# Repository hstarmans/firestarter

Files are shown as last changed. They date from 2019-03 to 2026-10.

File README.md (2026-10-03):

# Hexastorm PCB

KiCad design files for **Hexastorm**, an open-hardware laser direct imager (LDI). An ESP32-S3 handles communication and motion control, while an iCE40 UP5K FPGA generates synchronized laser pulses for the rotating polygon prism.

The design files are organized into two parts:

## 1. Laser Module

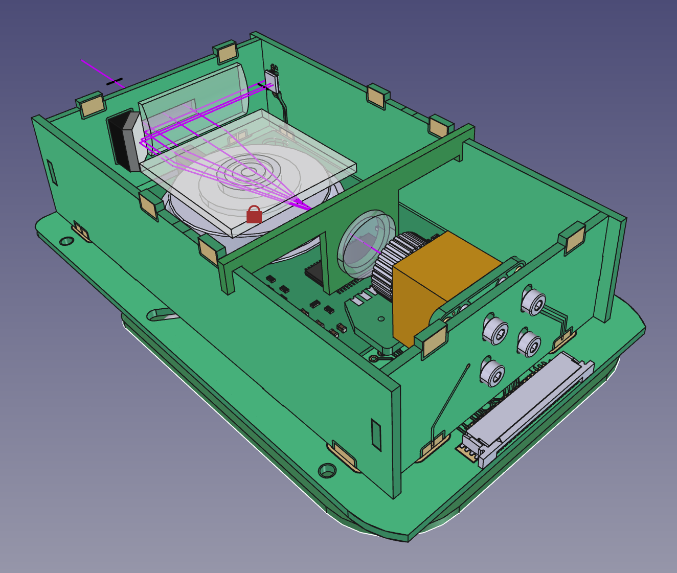
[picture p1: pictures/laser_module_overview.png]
Laser Module Assembly


PCBs forming the scanhead assembly (see [hexastorm_design](https://github.com/hstarmans/hexastorm_design) for complete CAD):

* **Prism Drive:** PCBs to spin the optical prism using either an external BLDC motor or an experimental PCB stator motor.
* **Laser Control:** Diode driver and photodiode sync circuit.
* **Maxwell Dock:** Receiver PCB with kinematic ball mounts and magnet sockets.

## 2. Base Board

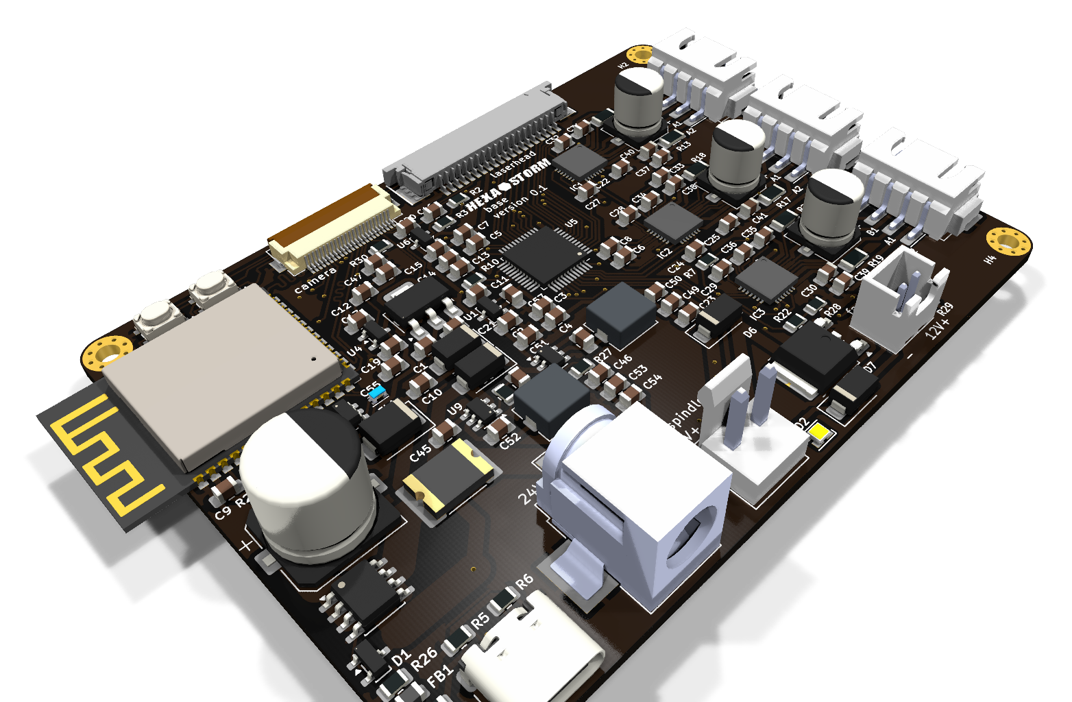
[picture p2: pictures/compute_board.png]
Hexastorm Compute Board


Single-board controller for 3-axis motion and laser timing. Intended for desktop CNC frames (such as the CNC 3018 Pro, for which it is a drop-in replacement):

* **MCU:** ESP32-S3 (N32R8V) with 8MB Octal PSRAM for line buffers.
* **FPGA:** Lattice iCE40 UP5K for laser pulse timing synced to the prism photodiode index.
* **Camera:** 24-pin FPC connector for an OV2640 camera module.
* **Motion:** Sockets for 3x stepper drivers (TMC2209) for X, Y, and Z axes.
* **Laser:** Header for one laser scanhead.
* **Power:** 24V input with onboard 12V buck regulator for the laser module and cooling fan.
* **USB:** USB-C for data and flashing.

---

# Resources & Links

* **Blog & Build Logs:** [Hackaday.io project](https://hackaday.io/project/21933-open-hardware-fast-high-resolution-laser)
* **BOM & Costing:** Generated with [KiCost](https://github.com/hildogjr/KiCost) (see [developer.md](developer.md))
* **CAD Files:** [hexastorm_design](https://github.com/hstarmans/hexastorm_design)
* **Optical Simulation:** [opticaldesign](https://github.com/hstarmans/opticaldesign)

# Status

* **Exposure Verification:** High-resolution optical scanning and exposure have been validated in hardware (see [demonstration video](https://youtu.be/dR09Tev0cPk)).
* **Base Board:** Fabricated, tested, and verified functional (ESP32-S3, iCE40 UP5K FPGA, stepper drivers, and power regulation).
* **Laser Module:** Scanhead structure, optics, diode driver, and kinematic docking are verified. The integrated PCB stator motor concept is proven, though the latest stator board revision has not yet been tested.

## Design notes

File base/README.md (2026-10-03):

# Hexastorm Compute Board

Hexastorm Compute Board

Main single-board controller for the Hexastorm laser direct imager (LDI). Integrates high-speed optical timing logic, motion control, and power distribution on a 4-layer PCB designed as a drop-in replacement for desktop CNC 3018 frames.

## Key Details
* **MCU:** ESP32-S3 (N32R8V) with 8MB Octal PSRAM for line buffers and web/USB interface
* **FPGA:** Lattice iCE40 UltraPlus 5K (UP5K) for nanosecond laser pulse timing synchronized to prism index
* **Motion:** Sockets for 3× TMC2209 stepper motor drivers (X, Y, Z axes)
* **Vision:** 24-pin FPC connector for an OV2640 alignment camera
* **Laser Interface:** High-density header for scanhead interconnect
* **Power:** 24V input with onboard 12V buck regulator and 3.3V power stages
* **Connectivity:** USB-C for flashing and high-speed data transfer

---
*Part of the [Hexastorm (Firestarter)](../README.md) open-hardware laser direct imaging project.*

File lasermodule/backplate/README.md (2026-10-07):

# Scanhead Back Plate

Scanhead Back Plate

Structural rear wall of the laser scanhead enclosure box, providing mechanical rigidity and fastener mounting points.
It supplies current to the laserdiode via two strips to laser module.

## Key Details
* **Role:** Rear structural wall of scanhead enclosure
* **Material:** 1.6mm FR4 PCB material

---
*Part of the [Hexastorm (Firestarter)](../../README.md) open-hardware laser direct imaging project.*

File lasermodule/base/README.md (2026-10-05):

# Scanhead Base Plate

Scanhead Base Plate

Structural bottom floor of the laser scanhead module. Hosts mounting holes for the prism motor assembly, internal optics brackets, and kinematic docking interfaces.
A female pinheader is shown but this one is normally not placed.

## Key Details

* **Role:** Bottom structural plate of scanhead housing
* **Material:** 1.6mm FR4 PCB material
* **Features:** Prism spindle mounting, beam pass-through cutouts, interlocking tabs

---

*Part of the [Hexastorm (Firestarter)](../../README.md) open-hardware laser direct imaging project.*

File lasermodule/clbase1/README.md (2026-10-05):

# Cylindrical Lens Base (clbase1)

Cylindrical Lens Base (clbase1)

PCB-based optical bracket holding the first cylinder lens with a focal length of 75 mm  securely in position along the scanhead optical beam path.

## Key Details

* **Function:** Cylindrical lens mounting bracket
* **Material:** Rigid FR4 for thermal and mechanical stability
* **Interface:** Interlocking slots for alignment inside the scanhead chassis

---

*Part of the [Hexastorm (Firestarter)](../../README.md) open-hardware laser direct imaging project.*

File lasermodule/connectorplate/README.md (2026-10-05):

# Scanhead Connector Plate

Scanhead Connector Plate

Interface place between the polygon motor and the base pcb.

## Key Details

* **Role:** Electrical interconnect interface for scanhead
* **Connectors:** High-density locking connector cutout and strain relief

---

*Part of the [Hexastorm (Firestarter)](../../README.md) open-hardware laser direct imaging project.*

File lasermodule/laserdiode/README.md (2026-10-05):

# Laser Diode Mount & Driver PCB

Laser Diode Mount & Driver PCB

Carrier PCB for the laser diode module inside the scanhead housing. Provides pogo-pin connection to the back plate of the laserhead. Solder contacts provide opton to determine pin routing.

## Key Details

* **Function:** Laser diode mounting and modulation interface
* **Contacts:** Spring-loaded pogo pin pads and direct solder pads for high-speed modulation driver connection
* **Form Factor:** Compact circular/rectangular footprint fitting diode heatsink assembly

---

*Part of the [Hexastorm (Firestarter)](../../README.md) open-hardware laser direct imaging project.*

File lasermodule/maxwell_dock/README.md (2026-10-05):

# Maxwell Kinematic Dock Receiver Plate

Maxwell Kinematic Dock Receiver Plate

Precision kinematic dock receiver PCB interface. Provides high-repeatability magnetic and kinematic mounting for quickly swapping or aligning the laser toolhead.
The three circular holes are for metal balls which are glued to the board. The four smaller holes are for M2 screw. The two keep out areas are for the axis of the mirror motor and 
the connector pins.

## Key Details

* **Mounting Principle:** Exact-constraint Maxwell kinematic clamp
* **Features:** Alignment ball sockets, magnetic clamp cutouts, and central laser pass-through
* **Repeatability:** Sub-pixel optical alignment repeatability after head replacement

---

*Part of the [Hexastorm (Firestarter)](../../README.md) open-hardware laser direct imaging project.*

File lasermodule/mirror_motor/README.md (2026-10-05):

# Polygon Mirror Motor Driver PCB

Polygon Mirror Motor Driver PCB

High-speed brushless motor driver PCB for driving the high-RPM rotating optical polygon mirror assembly. This board should not be built and is not functional.
It is used as virtual model for pcb of the sharp AR160 polygon motor.

## Key Details

* **Function:** Polygon mirror BLDC driver and timing feedback
* **Sensors:** Hall-effect sensor inputs for high-precision speed stabilization

---

*Part of the [Hexastorm (Firestarter)](../../README.md) open-hardware laser direct imaging project.*

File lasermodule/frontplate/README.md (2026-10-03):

# Scanhead Front Plate

Scanhead Front Plate

Front wall of the scanhead enclosure. Features the precision optical scan slit through which the reflected laser beam exits towards the exposure bed.

## Key Details
* **Role:** Front enclosure wall and beam exit window
* **Features:** Laser scan slit aperture and structural interlocking tabs

---
*Part of the [Hexastorm (Firestarter)](../../README.md) open-hardware laser direct imaging project.*

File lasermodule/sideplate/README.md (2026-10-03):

# Scanhead Side Plate

Scanhead Side Plate

Structural side wall of the scanhead housing. Features castellated/interlocking tabs for rigid 3D box construction using PCB material.

## Key Details
* **Role:** Structural side wall of scanhead
* **Construction:** Interlocking tabbed FR4 construction

---
*Part of the [Hexastorm (Firestarter)](../../README.md) open-hardware laser direct imaging project.*

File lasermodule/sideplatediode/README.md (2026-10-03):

# Scanhead Diode-Side Plate

Scanhead Diode-Side Plate

Structural side wall of the scanhead housing specifically accommodating the laser diode heatsink and mounting hardware.

## Key Details
* **Role:** Diode-side enclosure wall
* **Features:** Laser diode barrel heatsink cutout and mounting clearance

---
*Part of the [Hexastorm (Firestarter)](../../README.md) open-hardware laser direct imaging project.*

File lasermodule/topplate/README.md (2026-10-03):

# Scanhead Top Plate

Scanhead Top Plate

Top enclosure cover plate in FR4. Seals the optical cavity to prevent dust ingress and optical contamination on the spinning polygon prism and lenses.

## Key Details
* **Role:** Top protective dust cover of scanhead
* **Material:** 1.6mm FR4 PCB material
* **Assembly:** Interlocking tabs for solder/tab joint assembly

---
*Part of the [Hexastorm (Firestarter)](../../README.md) open-hardware laser direct imaging project.*

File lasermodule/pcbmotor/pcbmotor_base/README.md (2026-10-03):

# PCB Stator Motor Base

PCB Stator Motor Base

Experimental PCB stator motor base plate with planar copper coil windings for direct-drive polygon prism rotation.

## Key Details
* **Technology:** Integrated PCB stator windings
* **Status:** Experimental prototype design

---
*Part of the [Hexastorm (Firestarter)](../../../README.md) open-hardware laser direct imaging project.*

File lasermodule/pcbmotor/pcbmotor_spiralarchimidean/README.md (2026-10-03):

# Archimedean Spiral PCB Stator Motor

Archimedean Spiral PCB Stator Motor

Experimental planar PCB stator motor featuring Archimedean spiral trace windings for direct-drive polygon mirror actuation.

## Key Details
* **Winding Topology:** Archimedean spiral planar copper traces
* **Status:** Experimental prototype design for PCB motor study

---
*Part of the [Hexastorm (Firestarter)](../../../README.md) open-hardware laser direct imaging project.*

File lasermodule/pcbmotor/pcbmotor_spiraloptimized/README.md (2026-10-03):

# Optimized Spiral PCB Stator Motor

Optimized Spiral PCB Stator Motor

High-efficiency optimized planar coil PCB stator motor design engineered for uniform magnetic torque distribution across polygon mirror phases.

## Key Details
* **Winding Topology:** Optimized multi-layer planar spiral copper coils
* **Status:** Experimental prototype design for PCB motor study

---
*Part of the [Hexastorm (Firestarter)](../../../README.md) open-hardware laser direct imaging project.*

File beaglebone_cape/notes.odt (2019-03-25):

Author: Rik Starmans
Title: Notes for firestarter design

Abstract: Notes that were made while designing the Firestarter.

Screen:

There are several options for adding a screen.
I2C protocol 4D Systems 80 euro, but is too invasive and requires a CAPE.

Geekcreit 7 inch or 5 inch hdmi around 50 euro, requires HDMI and USB.
Manga Screen (kickstarter, elias bakken, 90 euro)

You want the ability to add a HDMI screen later. So do not use P8 pin 27 up to 46 and pin 9.28, 9.29 and 9.31, see link (http://elinux.org/Beagleboard:Cape_Expansion_Headers#Black_eMMC_and_HDMI_Pins).

Circuit protection

The diodes are for reverse polarity protection. They will blow instead of the circuit.
Blade fuses are used in cars. They are the cheapest and can be mounted on a PCB.

The trace width can be calculated here (http://circuitcalculator.com/wordpress/2006/01/31/pcb-trace-width-calculator/).

Stepper driver:

Stepper driver, you use the TMC. It is described here (https://hackaday.com/2016/09/30/3d-printering-trinamic-tmc2130-stepper-motor-drivers-shifting-the-gears/). You need an SPI port. You can only use SPI0 as the SPI1 is taken by HDMI, which implies 9.17, 9.18, 21 and 22.
Yes, a separate slave select per slave with the other signals in common is correct (https://radiostud.io/understanding-spi-in-raspberry-pi/). You can daisy-chain with TMC2130. If more than 40 clocks are driven, the additional bits shifted into SDI are shifted out on SDO after a 40-clock delay through an internal shift register. However, this was not used.
P9_22 (SPI0_SCLK => SCLK) outputs a serial clock signal to synchronize communications. P9_18 (SPI0_D1 => MOSI) outputs data to the SPI peripheral device.
P9_21 (SPIO_DO => MISO) receives data from the SPI peripheral device.
P9_17 (SPI0_CSO => CE0) enables one SPI peripheral device.

Digipot
For the Digipot you need I2C. You can’t use I2C1 as it requires 17 which is used for TMC. You can use I2C2 as it requires

19, 20.

Laser Extension board;

You contemplated on a laser extension board which could be hooked via a data cable. On a data cable, the red wire signals pin 1.
You would need at least the following pins

laserpin 1 (IC HB PWM1)
laserpin 2 (IC HB PWM2)
photodiode

potw (power laserdiode)

The point is it is not needed at the moment, you want the simplest design possible.

Motor cables:

AWG < AWG 17 around 1.7A max per NEMA 17 so total 3A

Expected currents:

Motor circuit

Nema 17 motor uses 1.7A at 12V, spindle (DC 775 motor) uses up to 25A. Typically, spindle uses 12A.
The safety circuit for the spindle does not handle this current.

Laser circuit
The driver can supply up to 300 mA.

Safety Circuit
The safety procedure is outlined here (http://www.diva-portal.org/smash/get/diva2:962662/FULLTEXT01.pdf). You start with a hazard identification. You then determine the measures and how they should be implemented (minimum category), see omron (http://www.omron.com.au/service_support/technical_guide/safety_component/safety_functions.asp).

The motor circuit and laser should be separate. You can then break the motor with an e-stop and the laser with a magnetic interlock. The machine cannot immediately start if the e-stop is closed.
The following is circuit is used (https://electronics.stackexchange.com/questions/182335/how-to-use-an-e-stop-rated-at-10a-for-higher-current-application) to reactivate the circuit with a start button, see safety relay (https://nl.farnell.com/finder/50-12-9-012-1000/relay-safety-dpdt-250vac-8a/dp/1329680?st=safety%20relay). The problem with any semiconductor device in a safety critical circuit is predicting failure modes, in general you can't. That’s why it can’t be used in a safety circuit. There are however solid-state relays for hazardous situations. I don’t know how they compare with force guided contacts.
If you design a safety guard, you should also take into account the distance to the hazard and how the guard opens (https://machinerysafety101.com/2012/06/01/interlocking-devices-the-good-the-bad-and-the-ugly/).
Besides the regulation you can also look at similar hardware, a tear down of the Form 2 can be found here (https://www.bunniestudios.com/blog/?p=4641). The company also hosts interactive 3D teardowns (https://formlabs.com/blog/form-2-interactive-3d-model/). Formlabs uses a magnetic interlock. It does not seem to be using any relays. Due to the limited budget and as we r designing MVP.

Pins low:
Build a script (https://stackoverflow.com/questions/24253383/how-to-set-gpios-to-be-low-on-startup)that pulls the pin low on startup to prevent problems.

Spindle control / Stepper motors
Add a e-stop which disables power to the motors by holding the reset pin low on the PSU.
The e-stop is more of a power button and does not include a start button. If the e-stop is de-actived the system powers on.

Laser Safety:

Use a an upward flip like Formlabs and a a magnetic interlock. Add a button so you can see whether power is supplied to the laser and turn it of or on.

Safety Switch:

MC1 440N Magnetic Safety Switch, Plastic (38.20 euro) uses reed contact so should work with lower voltages.

Spindle control
The spindle can be controlled via PWM. You can use a transistor or a MOSFET to PWM the spindle.

Transistor

A simple circuit can be found here (https://cdn.sparkfun.com/assets/resources/4/4/DC_motor_circuits_notes_2up.pdf). Calculations need to be made to select the correct NPN transistor are here (https://teachmetomake.wordpress.com/how-to-use-a-transistor-as-a-switch/). A PNP transistor should not be selected as it can only handle the same voltage. Motor is 150W at 12V, can draw at least 12A on video (https://www.youtube.com/watch?v=Gs8Ih83Vdv0) seems to be able to draw up to 25A. The amplifier is at least 750 so for 20.000 mA/750 = 27 mA.

Voltage drop can vary between from 3.3V to 1V or 2V. They resistor becomes than 2.3V/25mA=91 Ohm. Smaller might be required in some cases but could lead to trouble.

Looking at the result we select the following MJH6284 (http://www.farnell.com/datasheets/1911608.pdf)G (NPN).
An alternative is this PMD16K80 (https://nl.farnell.com/solid-state/pmd16k80/transistor-darl-npn-80v-20a-to3/dp/1863027). It can amplify more but does not look to be in a correct casing.

Transistors require a heatsink (http://www.learnabout-electronics.org/Amplifiers/amplifiers51.php). The power you want to dissipate is P=VI and most dominated by the collector voltage so P=12*10 (worst case). However, if you read the doc you see the Collector-Emitter saturation voltage is like 2 or 3V. So the power is 3*20=60 Watt (worst case).

For high current applications you can better use a MOSFET.

MOSFET

The IRLB8721PbF can be used up to 15A without cooling. The threshold voltage is 2.5V, see details (https://www.adafruit.com/product/355).
Use a 10 kOhm resistor to prevent a floating pin. You connect the PWM pin to the gate. The source to the ground and the drain to the negative pole of the motor. Schottky diodes are preferred in fly-back application because they have the lowest voltage drop

You need to PWM at least at 20kHz to prevent audible sound. The STPS1545D seems good enough.

Fan control:

The fan is controlled via a standard PWM pin. I don’t expect noise to be much of an issue.
The mosfet chosen is IRFML8244.

Extensions:
If you can want to connect multiple boards, you should use flat cable connectors. For simplicity,
all components were kept at one board.

Literature

The following information was also collected during the write up of the document.

Other 3D printer controller boards:

DUET

SMOOTHIE
REPLICAPE / REVOLVE (uses PRU); basically you can get the octavo; a beaglebone in a bga
RAMBO

If you want to bring it to a single board you can use the OSD3358 (octavo chip). This also forms the basis for the beaglebone pocket.

height sensor https://www.duet3d.com/DuetAddons/IRProbe (IR probe)

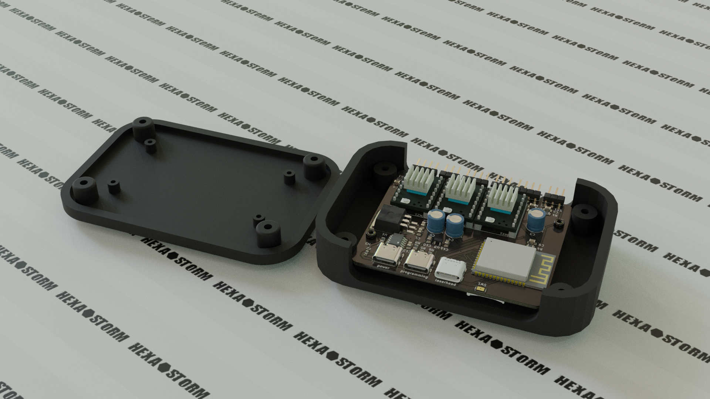
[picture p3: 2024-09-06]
pictures/hexastorm_mainboard.jpg

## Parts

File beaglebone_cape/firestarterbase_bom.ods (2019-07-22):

 | Qty | RefDes | Producer | Producer Part No | Farnell Part No | Farnell American | DigiKey Part No | SOS | Description
1 | 3 |  | MOLEX | 22-27-2041 | 9731164 (https://nl.farnell.com/molex/22-27-2041/connector-header-4pos-1row-2-54mm/dp/9731164) |  | WM4113 (https://www.digikey.com/products/en?keywords=WM4113-ND) |  | connector stepper motor
2 | 3 |  | MOLEX | 22-27-2031 | 9731156 (https://nl.farnell.com/molex/22-27-2031/connector-header-3pos-1row-2-54mm/dp/9731156) |  |  |  | endstop connection
3 | 1 |  | MULTICOMP | EBV-02-D | 2579770 (https://nl.farnell.com/multicomp/ebv-02-d/tb-wire-to-board-2pos-12awg/dp/2579770) |  |  |  | spindle connector
4 | 3 |  | MULTICOMP | MC000052 | 2008023 (https://nl.farnell.com/multicomp/mc000052/terminal-block-wire-to-brd-2pos/dp/2008023) |  |  |  | terminal block
5 | 1 |  | LITTELFUSE | 448002.MR | 1596928 (https://nl.farnell.com/littelfuse/0448002-mr/fuse-v-fast-acting-smd-2a/dp/1596928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) |  |  |  | 2A 12V fuse
6 | 1 |  | LITTELFUSE | 0448004MR | 1596929 (https://nl.farnell.com/littelfuse/044802-5mr/fuse-smd-2-5a-v-fast-acting/dp/1596929) |  |  |  | 2.5A 5V fuse
7 | 3 |  | PANASONIC | ECA-1VM101 | 9693670 (https://nl.farnell.com/panasonic/eca1vm101/cap-100-f-35v-20/dp/9693670) |  |  |  | caps for steppers
8 | 2 |  | SAMTEC | SSW-123-01-T-D | 2779596 (https://nl.farnell.com/samtec/ssw-123-01-t-d/connector-rcpt-46pos-2row-2-54mm/dp/2779596) |  |  | 2076-2x23 (https://www.sossolutions.nl/2076-2x23-male-headers-for-beaglebone-black-two-pack) | beaglebone receptable !! instead of headers
9 | 3 |  | ON SEMICONDUCTOR | S1A | 9843868 (https://nl.farnell.com/fairchild-semiconductor/s1a/diode-standard-1a-50v-smd/dp/9843868) |  |  |  | diode for circuit protection
10 | 2 |  | 3M | 929974-01-36-RK | 2064805 (https://nl.farnell.com/3m/929974-01-36-rk/socket-tht-pcb-36way/dp/2064805) | 2802332 (https://nl.farnell.com/mcm/rs1-06-g-413/1-x-6-position-female-socket-with/dp/2802332) |  |  | header stepper motor
11 | 1 |  | MULTICOMP | MCCQ-121 | 1586596 (https://nl.farnell.com/multicomp/mccq-121/fuseholder-pcb-mount-ato/dp/1586596) |  |  |  | ATO blade fuse holder, max current is 30A see Kicad
12 | 1 |  | INFINEON | IRLB8721PBF | 1740783 (http://www.farnell.com/datasheets/436505.pdf) |  |  |  | MOSFET spindle
13 | 1 |  | STMICROELECTRONICS | STPS1545D | 9803394 (https://nl.farnell.com/stmicroelectronics/stps1545d/diode-schottky-15a-45v/dp/9803394) |  |  |  | flyback diode spindle
14 | 3 |  | VISHAY | CRCW080510K0FKEA | 1469856 (https://nl.farnell.com/vishay/crcw080510k0fkea/res-10k-1-0-125w-0805-thick-film/dp/1469856) |  |  |  | resistor 10K
15 | 1 |  | MULTICOMP | MCATP-L-E 30A | 1569162 (https://nl.farnell.com/multicomp/mcatp-l-e-30a/fuse-automotive-ato-30a-with-led/dp/1569162) |  |  |  | blade fuse
kkk connectors
kkk crimp tool
wires
flat cable
flat cable crimp tool
molex female
long header pins to connect to board
not used
 | VISHAY | SS1H10-E3/61T | 9551301 (https://nl.farnell.com/vishay/ss1h10-e3-61t/diode-schottky-1a-100v/dp/9551301) |  |  |  | schottky rectifier for circuit protection, flyback diode fan

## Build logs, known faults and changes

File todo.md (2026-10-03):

# Things to do

  y - as werkt redelijk
    home apart je x en je y (maak dit knoppen), en beweeg niet zo veel naar een home move
    ga er bij printen van uit dat je gehomet ben en beweeg alleen naar de absolute positie, zet verder de safety uit, hiermee moet je het voor nu redden

  correctie laserhead is niet bewezen
  foto maken met camera lukt niet
  er is geen buffer flush commando
  de motion core verstuud de abc coefficienten en niet de gecorrigeerde
  g-code verwerken niet mogelijk
  test-opstelling niet uitgelijnd

  fix dat je led kan aanzetten
  homing wordt niet goed verwerkt in de interface

  lijn de camera uit

er is een nieuwe eps32 chip uitgekomen de s31
niet alle pinnen zijn verbonden van de esp32s3 je zou deze via solder jumpers kunnen verbinden aan de chip (dan heb je de optie!)
de laserhead moet verbeterd worden (hoe je de motor er in zet, magnetic mounting)
je zou een PID controller op je spindle kunnen zetten

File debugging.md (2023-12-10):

# Photodiode circuit
PCB for detecting the start of a scanline of a laser scanner by amplifying signal with opamp and then reading it out via Schmitt trigger.
Circuit was copied from earlier work by [Henner Zeller](https://github.com/hzeller/ldgraphy/tree/master/pcb/cape).
A blue enhanced photodiode is not required. 
The photodiode cathode, which is marked, should be connected to ground. If you measure resistance in reverse direction, i.e. ground is positive,
you should measure around 250 kOhms. In normal operation, i.e. ground is ground, resistance should be infinite. In practice, you could measure 0.5 MOHm,
as you can also reach ground via the opAMp. Once the circuit is turned on, the anode of the  photo-diode should measure 1.1 volt.
If you measure something lower, this could indicate that the directly connected opamp is blown.  
Once the photodiode is illuminated, voltage should drop to zero volt. On the location of the test point you should measure more than 3 volts and 0.6 volts
in dark and light situation respectively.

## Debugging
Resistance between 5V and GND is now 40 Ohms.
In an earlier circuit, the photodiode circuit was separated. Here, resistance between 5V and GND should be 9 kOhm.
Resistance between Signal and GND should be 6 kOhm. 

## Trivia
[Hamamatsu](https://www.hamamatsu.com) sells dedicated IC's like the S9684 series which have these circuits integrated.
In an earlier version, a simple voltage divider was used to read out the photodiode. This actually worked if the photodiode was combined with a cap to filter
out stray light.
The photodiode should work fine without cap and requires quite some light to trigger. 

# Lasers
The number one cause of death of a laser is ESD. Ensure you are properly grounded. If a laser is connected wrongly it does not turn on but will not break.

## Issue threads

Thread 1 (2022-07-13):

README needs should describe boards

GravisZro, 2022-07-13:
This repo is full of lots of PCBs but there is no explanation of what each one is or how they relate.  This should be clarified in the README for the repo.

hstarmans, 2022-07-13:
Gratis, as always you r right!! I will look into it.

Op wo 13 jul. 2022 20:07 schreef Gravis ***@***.***>:

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

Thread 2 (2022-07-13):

A new branch per iteration.

GravisZro, 2022-07-13:
With each new iteration of the scanner, a new branch should be made and any boards not used in the new iteration should be removed.  It's possible (but tricky and potentially dangerous) to rewrite the git history post-facto.  If you add tags for the start of each new iteration, I can help fix up the repo history so that it is branched in this manner.

hstarmans, 2023-04-29:
@GravisZro this has been done for the current iteration, hope this solves your issues.

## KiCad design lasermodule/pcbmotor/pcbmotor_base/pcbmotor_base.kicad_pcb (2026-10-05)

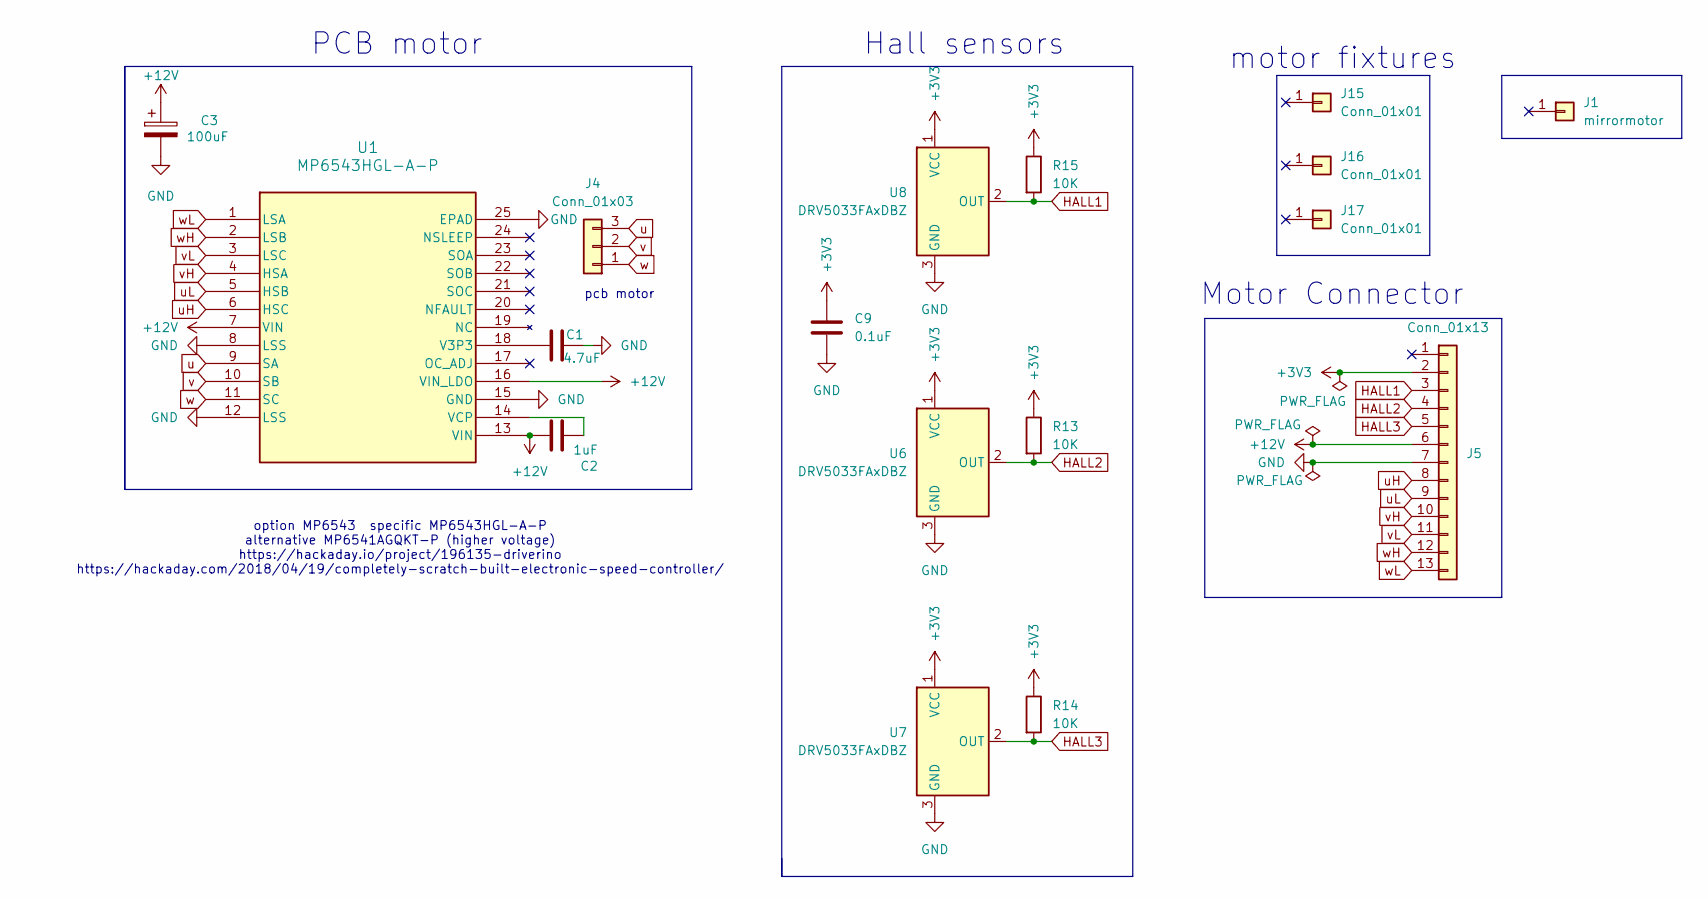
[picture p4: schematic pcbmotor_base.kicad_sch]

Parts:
C1: 4.7uF; C_0805_2012Metric; mouser# 81-GRM21BR61H475KE1L
C2: 1uF; C_0805_2012Metric; mouser# 581-08055C105KAT2A; farnell# 2094043
C3: 100uF; CP_Elec_6.3x5.4; mouser# 710-865080343009; farnell# 2466283
C9: 0.1uF; C_0805_2012Metric_Pad1.18x1.45mm_HandSolder; mouser# 80-C0805C104J5R
J1: mirrormotor; mirror_motor
J4: Conn_01x03; pcbmotor_smd
J5: Conn_01x13; motor_13pin
J15, J16, J17: Conn_01x01; TestPoint_Pad_D2.5mm_nosilk
R13, R14, R15: 10K; R_0805_2012Metric_Pad1.20x1.40mm_HandSolder; mouser# 71-CRCW080510K0JNEAC
U1: MP6543HGL-A-P; QFN-24-1EP_3x4mm_P0.4mm_EP1.65x2.65mm_ThermalVias; mouser# 946-MP6543HGL-A-P
U6, U7: DRV5033FAxDBZ; SOT-23; mouser# 595-RV5033FAEDBZRQ1
U8: DRV5033FAxDBZ; SOT-23; mouser# 595-RV5033FAEDBZRQ1; farnell# 3006067

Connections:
+3V3: C9.1, J5.2, R13.1, R14.1, R15.1, U6.1 (VCC), U7.1 (VCC), U8.1 (VCC)
+12V: C2.1, C3.1, J5.6, U1.7 (VIN), U1.13 (VIN), U1.16 (VIN_LDO)
GND: C1.1, C3.2, C9.2, J5.7, U1.8 (LSS), U1.12 (LSS), U1.15 (GND), U1.25 (EPAD), U6.3 (GND), U7.3 (GND), U8.3 (GND)
HALL1: J5.3, R15.2, U8.2 (OUT)
HALL2: J5.4, R13.2, U6.2 (OUT)
HALL3: J5.5, R14.2, U7.2 (OUT)
unnamed: C1.2, U1.18 (V3P3)
unnamed: C2.2, U1.14 (VCP)
u: J4.3, U1.9 (SA)
uH: J5.8, U1.6 (HSC)
uL: J5.9, U1.5 (HSB)
v: J4.2, U1.10 (SB)
vH: J5.10, U1.4 (HSA)
vL: J5.11, U1.3 (LSC)
w: J4.1, U1.11 (SC)
wH: J5.12, U1.2 (LSB)
wL: J5.13, U1.1 (LSA)

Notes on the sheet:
PCB motor
Motor Connector
Hall sensors
pcb motor
motor fixtures
option MP6543 specific MP6543HGL-A-P alternative MP6541AGQKT-P (higher voltage) https://hackaday.io/project/196135-driverino https://hackaday.com/2018/04/19/completely-scratch-built-electronic-speed-controller/

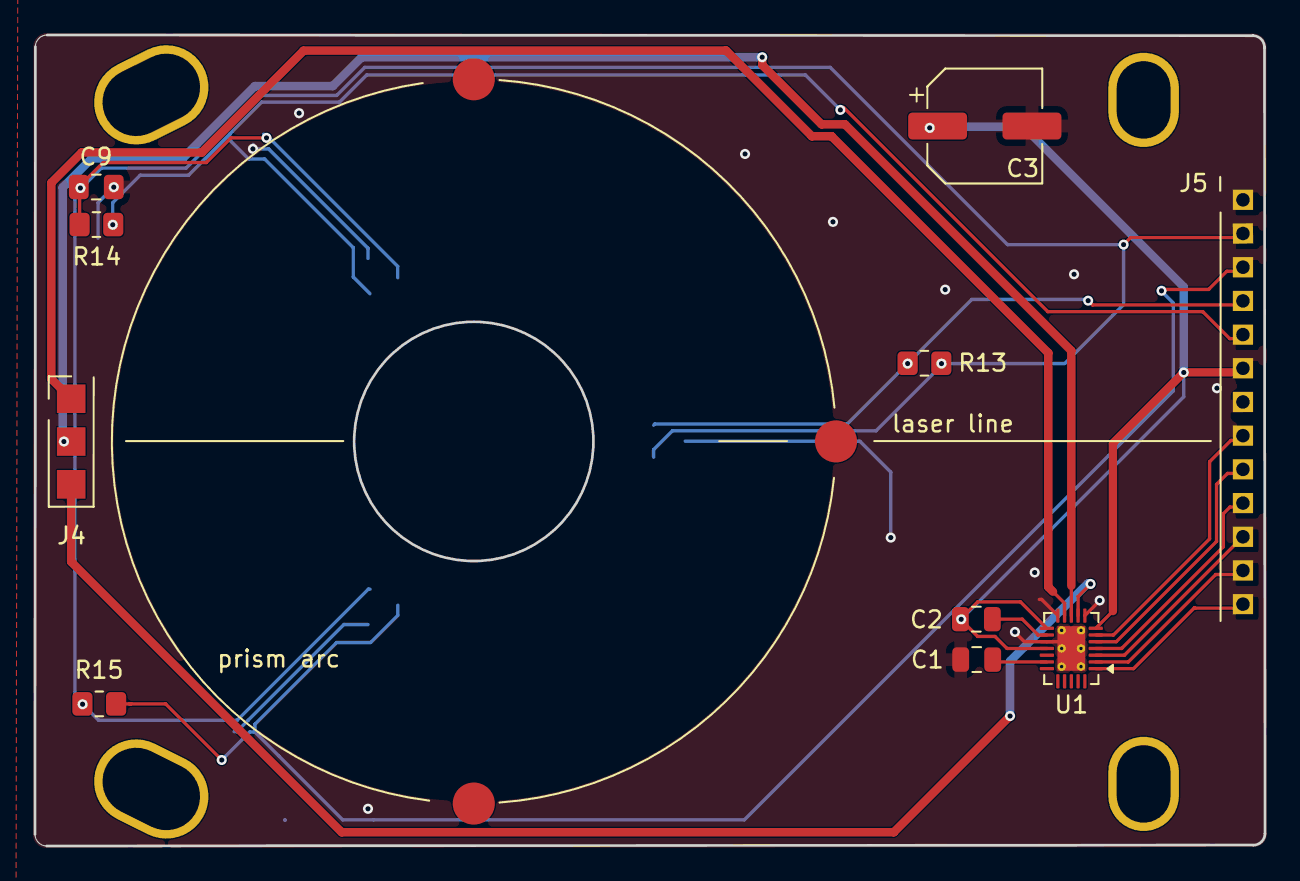
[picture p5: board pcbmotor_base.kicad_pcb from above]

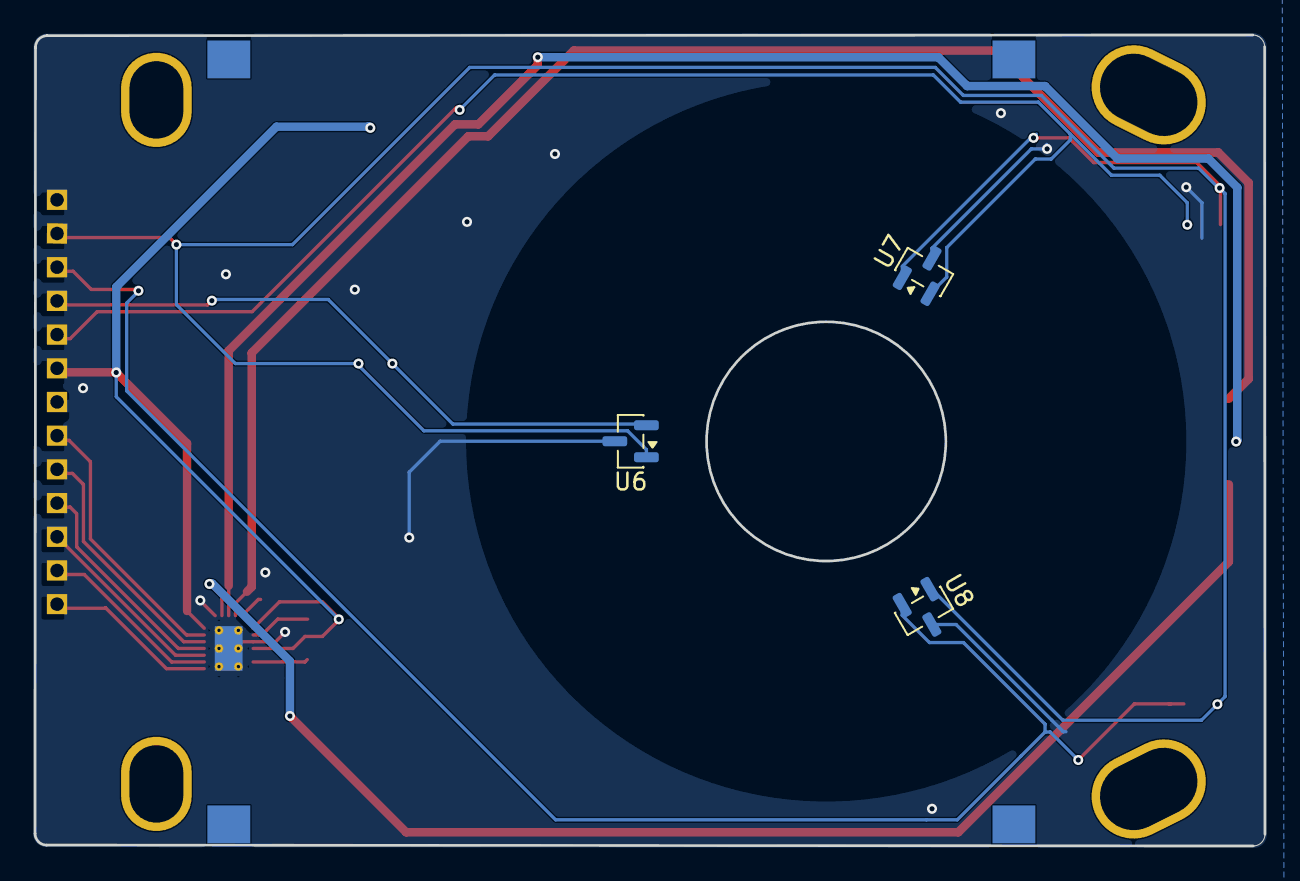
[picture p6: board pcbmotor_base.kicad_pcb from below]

Board: 2 copper layers, 73.0 x 48.1 mm, 17 parts (3 on the bottom side), 17 nets.

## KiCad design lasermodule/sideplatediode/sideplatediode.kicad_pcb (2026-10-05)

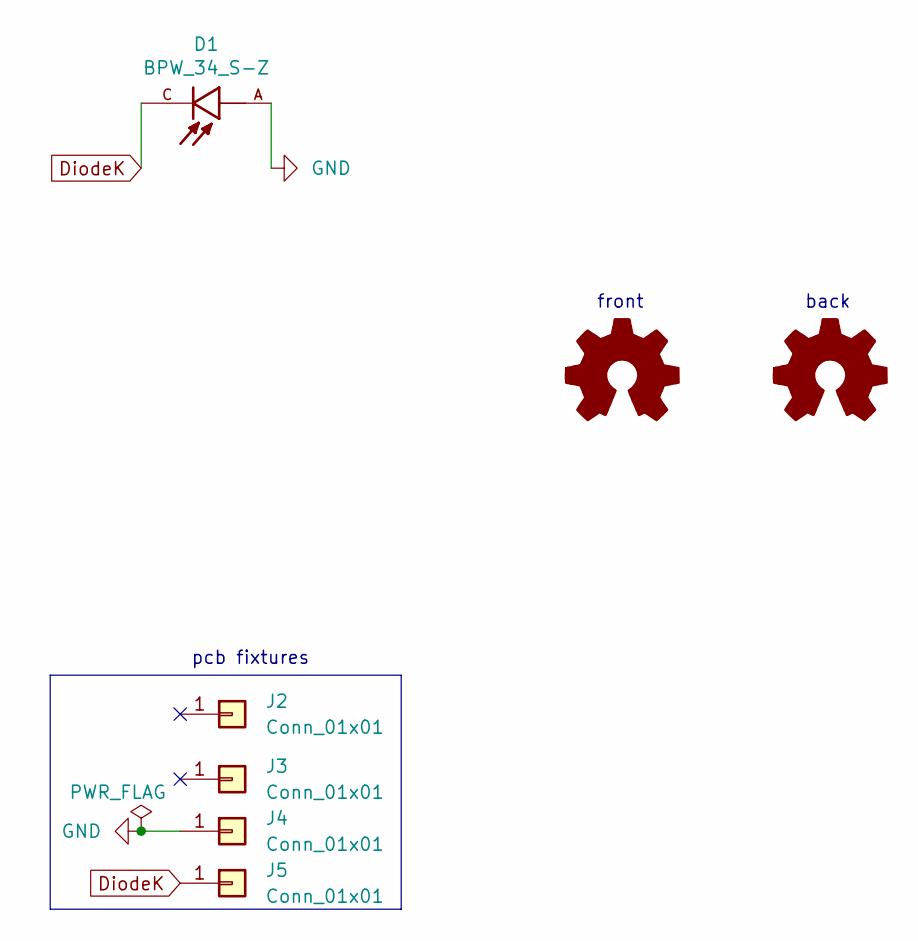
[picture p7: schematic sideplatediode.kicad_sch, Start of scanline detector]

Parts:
D1: BPW_34_S-Z; DIO_BPW_34_S-Z; manuf# BPW 34 S; mouser# 720-BPW34S-Z
J2, J3, J4, J5: Conn_01x01; TestPoint_Pad_2.0x2.0mm_nosilk
L1, L2: Logo_Open_Hardware_Small; hexastorm

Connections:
DiodeK: D1.C, J5.1 (Pin_1_1)
GND: D1.A, J4.1 (Pin_1_1)

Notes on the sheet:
back
pcb fixtures
front

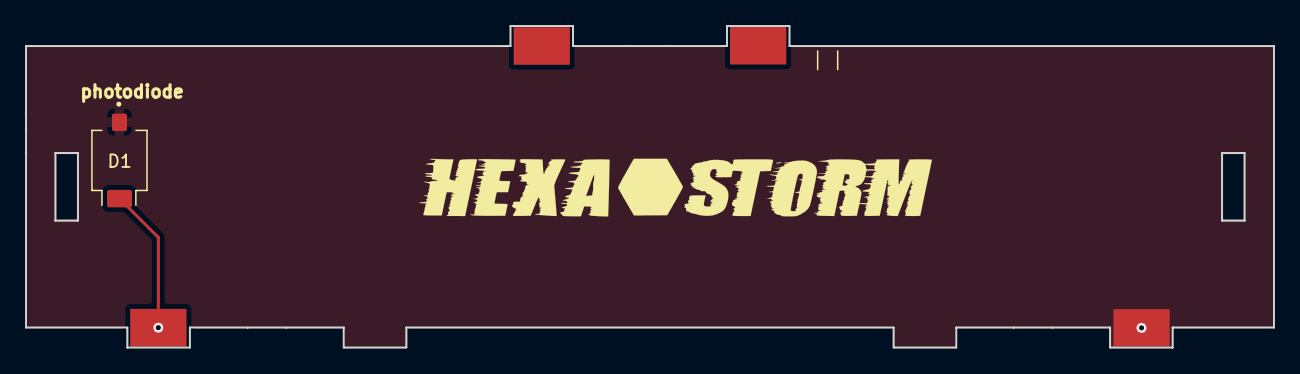
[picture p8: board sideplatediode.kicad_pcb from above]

Board: 2 copper layers, 99.8 x 25.7 mm, 7 parts (1 on the bottom side), 2 nets.

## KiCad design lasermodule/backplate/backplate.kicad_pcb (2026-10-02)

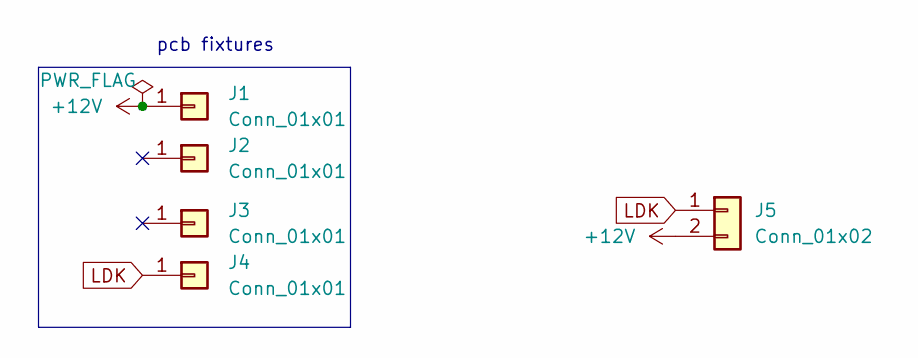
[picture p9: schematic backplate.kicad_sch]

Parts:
J1, J2, J3, J4: Conn_01x01; TestPoint_Pad_2.0x2.0mm_nosilk
J5: Conn_01x02; pogopincontact

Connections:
+12V: J1.1 (Pin_1_1), J5.2
LDK: J4.1 (Pin_1_1), J5.1

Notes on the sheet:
pcb fixtures

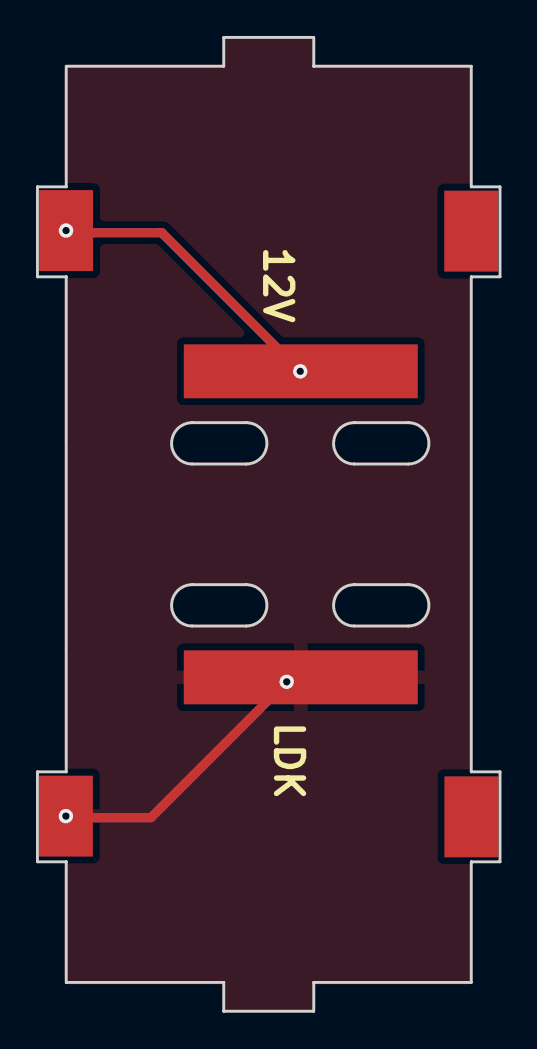
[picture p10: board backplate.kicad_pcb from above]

Board: 2 copper layers, 25.7 x 54.1 mm, 5 parts (0 on the bottom side), 2 nets.

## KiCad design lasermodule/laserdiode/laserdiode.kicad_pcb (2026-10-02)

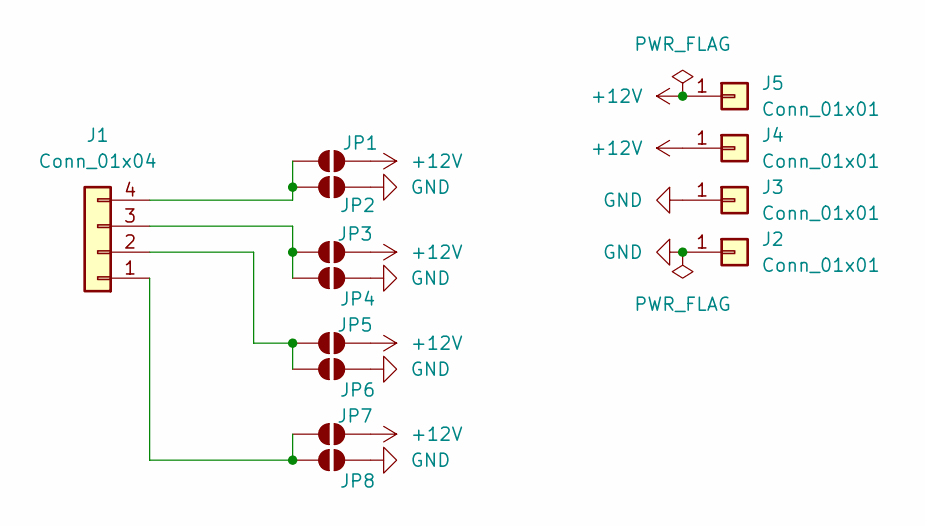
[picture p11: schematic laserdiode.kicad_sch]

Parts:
J1: Conn_01x04; TO-18-4
J2, J3, J4: Conn_01x01; 0906115207514110; manuf# 0906-1-15-20-75-14-11-0; Mouser 575-906115
J5: Conn_01x01; 0906115207514110; manuf# 0906-1-15-20-75-14-11-0; mouser# 575-906115
JP1, JP2, JP3, JP4, JP5, JP6, JP7, JP8: SolderJumper_2_Open; SolderJumper-2_P1.3mm_Open_RoundedPad1.0x1.5mm

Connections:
+12V: J4.1 (Pin_1_1), J5.1 (Pin_1_1), JP1.2 (B), JP3.2 (B), JP5.2 (B), JP7.2 (B)
GND: J2.1 (Pin_1_1), J3.1 (Pin_1_1), JP2.2 (B), JP4.2 (B), JP6.2 (B), JP8.2 (B)
unnamed: J1.1, JP7.1 (A), JP8.1 (A)
unnamed: J1.2, JP5.1 (A), JP6.1 (A)
unnamed: J1.3, JP3.1 (A), JP4.1 (A)
unnamed: J1.4, JP1.1 (A), JP2.1 (A)

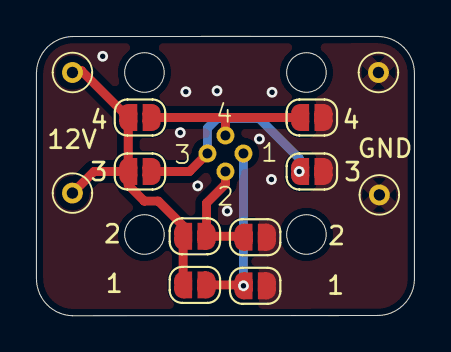
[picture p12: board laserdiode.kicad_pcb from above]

Board: 2 copper layers, 21.0 x 15.5 mm, 13 parts (1 on the bottom side), 6 nets.

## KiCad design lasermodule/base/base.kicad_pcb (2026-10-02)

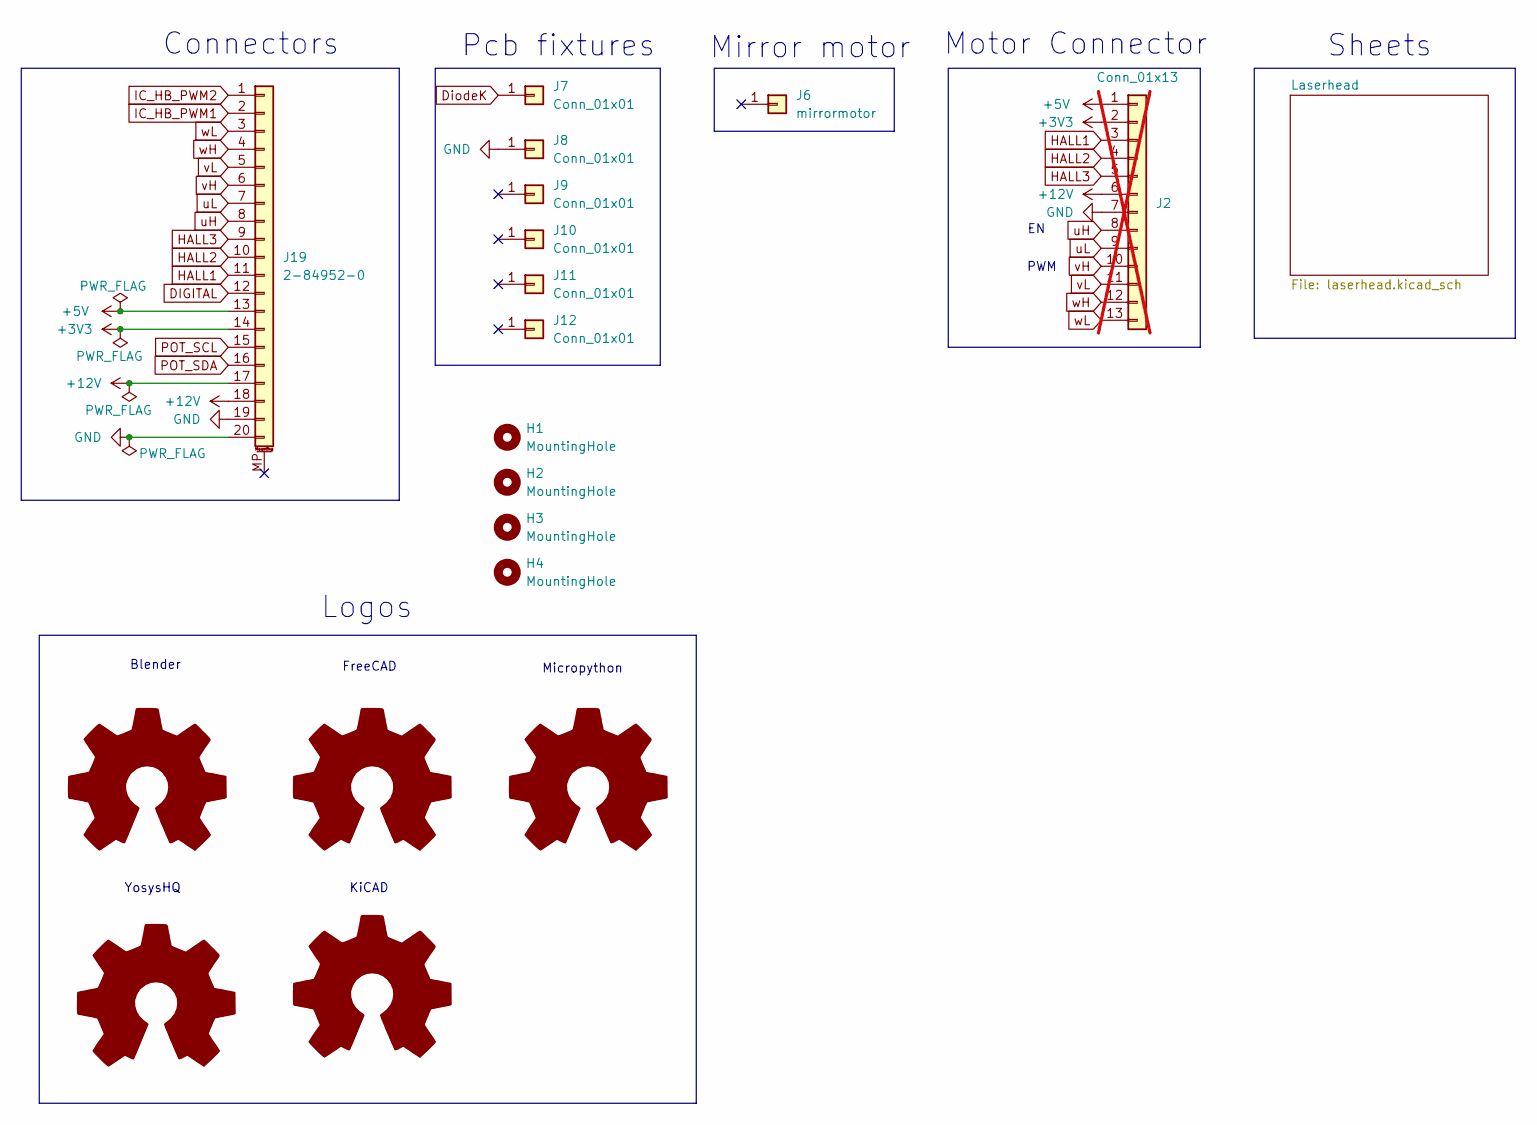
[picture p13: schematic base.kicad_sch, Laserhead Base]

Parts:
H1, H2, H3, H4: MountingHole; MountingHole_2.2mm_M2; mouser# 710-970050244
J2: Conn_01x13; PinSocket_1x13_P2.00mm_Vertical; not fitted
J6: mirrormotor; mirror_motor
J7, J8, J9, J10, J11, J12: Conn_01x01; throughholeplate
J19: 2-84952-0; mouser# 571-2-84952-0
L1: Logo_Open_Hardware_Large; blender
L2: Logo_Open_Hardware_Large; yosys
L3: Logo_Open_Hardware_Large; kicad
L4: Logo_Open_Hardware_Large; freecad
L5: Logo_Open_Hardware_Large; micropython

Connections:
+3V3: J2.2, J19.14
+5V: J2.1, J19.13; also elsewhere on the board
+12V: J2.6, J19.17, J19.18; also elsewhere on the board
DIGITAL: J19.12; also elsewhere on the board
DiodeK: J7.1 (Pin_1_1); also elsewhere on the board
GND: J2.7, J8.1 (Pin_1_1), J19.19, J19.20; also elsewhere on the board
HALL1: J2.3, J19.11
HALL2: J2.4, J19.10
HALL3: J2.5, J19.9
IC_HB_PWM1: J19.2; also elsewhere on the board
IC_HB_PWM2: J19.1; also elsewhere on the board
POT_SCL: J19.15; also elsewhere on the board
POT_SDA: J19.16; also elsewhere on the board
uH: J2.8, J19.8
uL: J2.9, J19.7
vH: J2.10, J19.6
vL: J2.11, J19.5
wH: J2.12, J19.4
wL: J2.13, J19.3

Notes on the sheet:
PWM
Micropython
YosysHQ
FreeCAD
Logos
KiCAD
Motor Connector
Blender
Connectors
Sheets
Mirror motor
Pcb fixtures

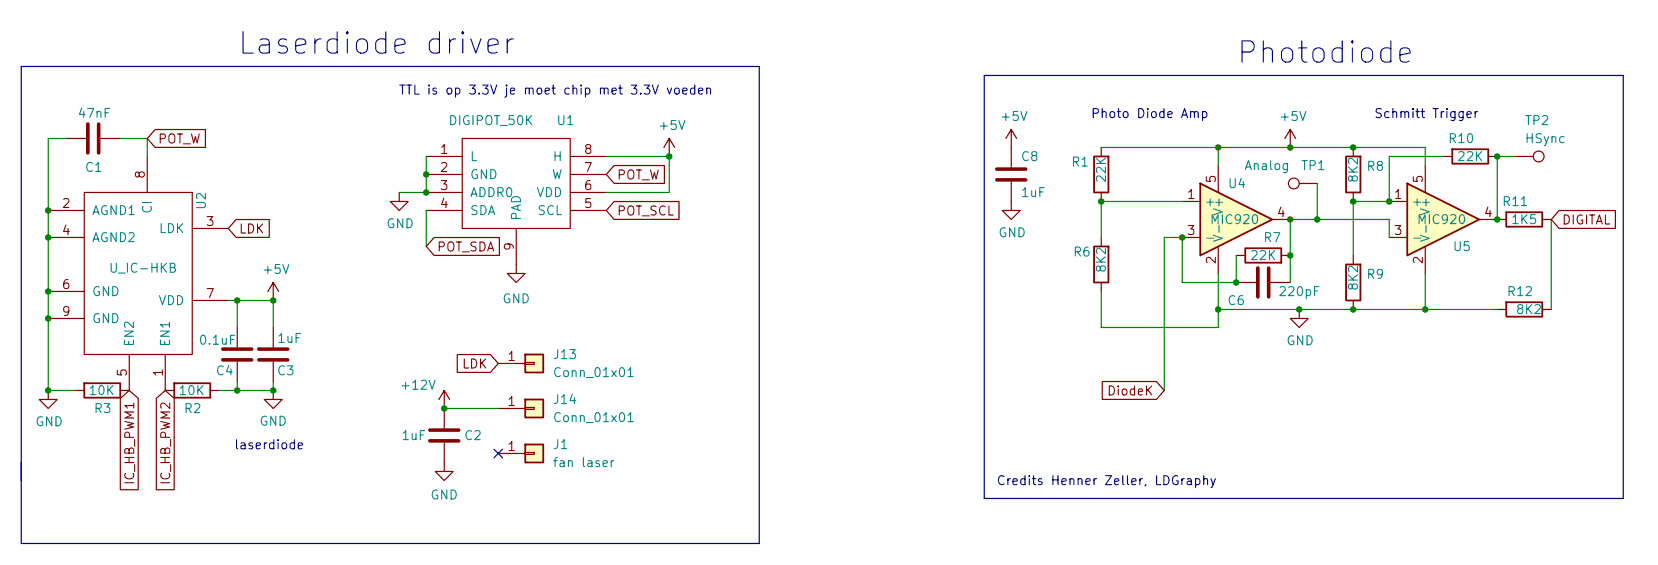
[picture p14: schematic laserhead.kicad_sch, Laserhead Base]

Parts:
C1: 47nF; C_0805_2012Metric_Pad1.18x1.45mm_HandSolder; mouser# 77-VJ0805Y473JXXCBC
C2, C8: 1uF; C_0805_2012Metric_Pad1.18x1.45mm_HandSolder; mouser# 581-08055C105KAT2A; farnell# 2094043
C3: 1uF; C_0805_2012Metric_Pad1.18x1.45mm_HandSolder; mouser# 581-08055C105KAT2A
C4: 0.1uF; C_0805_2012Metric_Pad1.18x1.45mm_HandSolder; mouser# 80-C0805C104J5R; farnell# 1414663
C6: 220pF; C_0805_2012Metric_Pad1.18x1.45mm_HandSolder; mouser# 80-C0805C221J5GAUTO
J1: fan laser; mouser# 490-HSB01-080808
J13, J14: Conn_01x01; throughholeplate
R1, R7, R10: 22K; R_0805_2012Metric_Pad1.20x1.40mm_HandSolder; mouser# 594-MCU08050C2202FP5
R2, R3: 10K; R_0805_2012Metric_Pad1.20x1.40mm_HandSolder; mouser# 71-CRCW080510K0JNEAC; farnell# 2826162
R6, R8, R9, R12: 8K2; R_0805_2012Metric_Pad1.20x1.40mm_HandSolder; mouser# 652-CR0805FX-8251ELF
R11: 1K5; R_0805_2012Metric_Pad1.20x1.40mm_HandSolder; mouser# 652-CR0805JW-152ELF
TP1: Analog; TestPoint_Pad_D1.0mm
TP2: HSync; TestPoint_Pad_D1.0mm
U1: DIGIPOT_50K; TDFN-8-1EP; mouser# 700-MAX5395MATA+T
U2: U_IC-HKB; ICHKB
U4: MIC920; SOT-353_SC-70-5; mouser# 998-MIC920YC5TR
U5: MIC920; SOT-353_SC-70-5; mouser# 998-MIC920YC5TR; farnell# 2920854

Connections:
+5V: C3.2, C4.2, C8.1, R1.2, R8.2, U1.6 (VDD), U1.8 (H), U2.7 (VDD), U4.5 (V+), U5.5 (V+); also elsewhere on the board
+12V: C2.2, J14.1 (Pin_1_1); also elsewhere on the board
DIGITAL: R11.1, R12.1; also elsewhere on the board
DiodeK: C6.2, R7.1, U4.3 (-); also elsewhere on the board
GND: C1.1, C2.1, C3.1, C4.1, C8.2, R2.1, R3.2, R6.1, R9.1, R12.2, U1.1 (L), U1.2 (GND), U1.3 (ADDR0), U1.9 (PAD), U2.2 (AGND1), U2.4 (AGND2), U2.6 (GND), U2.9 (GND), U4.2 (V-), U5.2 (V-); also elsewhere on the board
IC_HB_PWM1: R3.1, U2.5 (EN2); also elsewhere on the board
IC_HB_PWM2: R2.2, U2.1 (EN1); also elsewhere on the board
LDK: J13.1 (Pin_1_1), U2.3 (LDK)
unnamed: R10.1, R11.2, TP2.1 (1_1), U5.4
unnamed: R1.1, R6.2, U4.1 (+)
unnamed: R8.1, R9.2, R10.2, U5.1 (+)
unnamed: C6.1, R7.2, TP1.1 (1_1), U4.4, U5.3 (-)
POT_SCL: U1.5 (SCL); also elsewhere on the board
POT_SDA: U1.4 (SDA); also elsewhere on the board
POT_W: C1.2, U1.7 (W), U2.8 (CI)

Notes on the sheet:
Photo Diode Amp
TTL is op 3.3V je moet chip met 3.3V voeden
Laserdiode driver
Schmitt Trigger
Credits Henner Zeller, LDGraphy
laserdiode
Photodiode

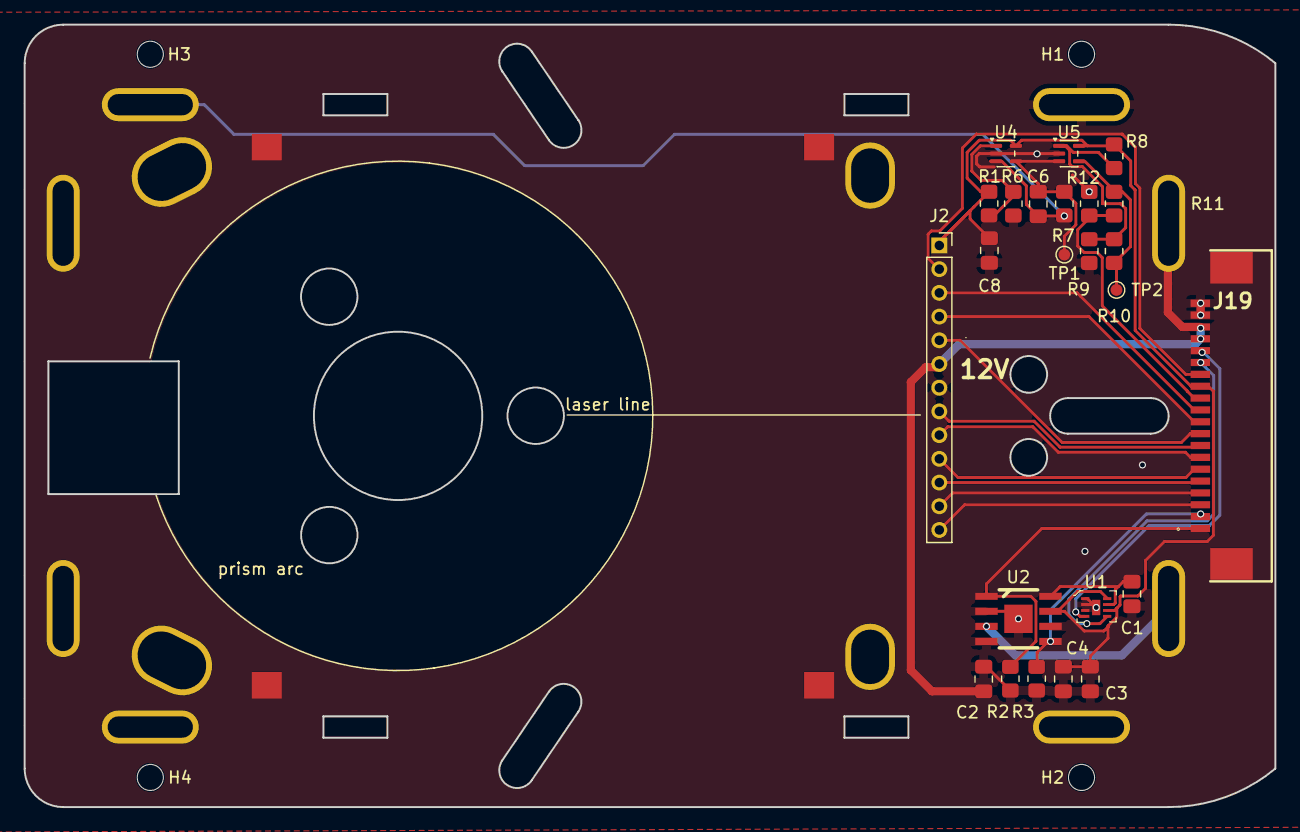
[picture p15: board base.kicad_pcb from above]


Board: 2 copper layers, 105.5 x 66.0 mm, 42 parts (5 on the bottom side), 25 nets.

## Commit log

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2018-12-04 added first sketch of board
    [hexastormhat-2018-12-04-21-13-52.sch, hexastormhat-2018-12-04-22-47-14.sch, hexastormhat.kicad_pcb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]
2018-12-05 last commit was from old raspb pi trial, this is the new version for beaglebonee
    [BeagleBone-Black-Cape.kicad_pcb, BeagleBone-Black-Cape.sch, hexastormhat-2018-12-04-21-13-52.sch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]
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2019-01-24 added some parts to bom and notes
    [firestarterbase_bom.ods]
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2019-03-13 proceeded with schematics, added most pins and layed out stepper motors
    [BeagleBone-Black-Cape.sch]
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2019-03-20 added psu connection plus protection updated components list added library part for digipot and laserdiode driver
    [BeagleBone-Black-Cape.sch, firestarterbase_bom.ods]
2019-03-24 finalized schematic, added PWM for fan.
    [BeagleBone-Black-Cape.sch, firestarterbase_bom.ods]
2019-03-25 updated components and links to datasheets
    [BeagleBone-Black-Cape.sch, firestarterbase_bom.ods]
2019-03-27 added footprints resistors and molex connectors
    [BeagleBone-Black-Cape.sch, firestarterbase_bom.ods]
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2019-04-02 added footprint for ichkb and renamed other footprints
    [BeagleBone-Black-Cape.sch]
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2019-04-08 finilazed schematics, removed some bugs and added footprint power connector
    [BeagleBone-Black-Cape.sch, firestarterbase_bom.ods]
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2019-04-15 fixed relative imports, started reorganizing pcb
    [BeagleBone-Black-Cape.kicad_pcb, BeagleBone-Black-Cape.sch]
2019-04-15 moved power connector into direction of ethernet port idea is that board is placed on male headers to create more space
    [BeagleBone-Black-Cape.kicad_pcb, BeagleBone-Black-Cape.sch]
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2019-04-17 added ground and power plane restored of 0, 5, 12, 24v connectors
    [BeagleBone-Black-Cape.kicad_pcb]
2019-04-18 finished routing board....
    still need to final check, add some text and make crucial tracks wider
    [BeagleBone-Black-Cape.kicad_pcb, BeagleBone-Black-Cape.sch]
2019-04-19 added extra tracks to improve current throughput board moved components as some would collide according to spec still need to add reference markers
    [BeagleBone-Black-Cape.kicad_pcb]
2019-04-23 footprint stepper motors was incorrect, this has been fixed
    [BeagleBone-Black-Cape.kicad_pcb, BeagleBone-Black-Cape.sch, firestarterbase_bom.ods]
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2019-04-29 updated components and added approximate cost of three boards
    [BeagleBone-Black-Cape-B.Cu.gbr, BeagleBone-Black-Cape-B.Mask.gbr, BeagleBone-Black-Cape-Edge.Cuts.gbr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]
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2019-09-12 fixed xpo pin connection
    [BeagleBone-Black-Cape.kicad_pcb, photodiode_cape.kicad_pcb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]
2019-09-23 tried to fix components that couldn't be viewed on linux
    [BeagleBone-Black-Cape.sch, scanhead_pcb.kicad_pcb, scanhead_pcb.sch]
2019-09-23 fixed library error
    [photodiode_cape.sch]
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2019-11-05 fixed quantity errors in bom
    [scanheadpcb_bom.ods]
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2020-05-03 updated bom and shematic with a couple of caps and resistors
    [firestarterbase_bom.ods, raspberrypi-gpio-40pin.sch]
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2020-05-13 continued routing, 3V and GND not fully connected
    [raspberrypi-gpio-40pin.kicad_pcb, raspberrypi-gpio-40pin.sch]
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2020-06-23 improved pcb
    made pincompatible with icezero SPI ports
    simplified PCB, reduced capacitors and removed 3V creator
    [raspberrypi-gpio-40pin.kicad_pcb, raspberrypi-gpio-40pin.sch]
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2021-07-18 changed most cables to flatex or jumper wire moved from 1 diode to 2 diodes added spi readout chip for photodiode photodiode is now surface mount
    [bomlist.ods, photodiode_cape.kicad_pcb, photodiode_cape.sch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]
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2021-07-30 decided to move to ice40up5k
    reasons cheaper chip, easier and has a DSP.
    [raspberrypi-gpio-40pin.sch, scanhead_pcb.sch]
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2021-10-01 fixed orientation connector laserdiode connector to correct side
    [raspberrypi-gpio-40pin.kicad_pcb, scanhead_pcb.kicad_pcb, scanhead_pcb.sch]
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2021-10-08 new cryled footprint changed footprint FPGA to simply debug
    [firestarterbase_bom.ods, raspberrypi-gpio-40pin.kicad_pcb, raspberrypi-gpio-40pin.sch]
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2021-12-28 pins wrongly denoted on schematic
    [base.sch]
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2022-01-28 moved to kicad 6 and added bom for ESP32 shield
    [ESP32_Shield.kicad_pcb, ESP32_Shield.kicad_sch, ESP32_shield_bom.ods]
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2023-05-11 further cleaned up and tested renders in blender
    [base.kicad_pcb, base.kicad_sch, fpga.kicad_sch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]
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2023-10-12 flatex cable increased from 15 to 20 pins
    [base.kicad_pcb, base.kicad_sch, fpga.kicad_sch]
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2024-08-18 moved from 2 headers to 1 smt 40 pin header
    [esp32.kicad_sch, main_board.kicad_pcb, main_board.kicad_sch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]
2024-08-22 moved stepper drivers to board, added smt connection for compute
    [main_board.kicad_sch, motors.kicad_sch]
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2024-09-06 added git lfs, model for polygon mirror motor
    [TB67S149FG,EL.stp, mirrormotor.kicad_sch]
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2024-10-28 improved position esp32, kicost integration fix for compute module
    [main_board.kicad_pcb, main_board.kicad_sch, motors.kicad_sch]
2024-10-28 added kicost tracking other plates, fixed plates
    [backplate.kicad_pcb, backplate.kicad_sch, base.kicad_pcb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]
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2024-10-31 fixed boms, small modifications to the boards.
    [esp32.kicad_sch, main_board.kicad_pcb, main_board.kicad_sch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]
2024-11-03 improved connection between pcb motor and base plate
    [base.kicad_pcb, laserhead.kicad_sch, pcbmotor_base.kicad_sch]
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2024-11-15 added pcb files, added offset between compute and extension
    [laserdiode.kicad_pcb, main_board.kicad_pcb, main_board.kicad_sch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]
2024-11-17 fixed typo, added standoff lasermodule
    [base.kicad_pcb, base.kicad_sch, fpga.kicad_sch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]
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2024-12-14 fixes some mistake in the bom found in first assembly
    [base.kicad_sch, compute.kicad_sch, extension.kicad_sch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]
2025-01-26 fixed issues uncovered with extension module
    [extension.kicad_pcb, extension.kicad_sch]
2025-01-26 fixed headers, shifted text base board
    [base.kicad_pcb, base.kicad_sch, compute.kicad_sch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]
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2025-01-29 fixed pullups i2c
    [esp32.kicad_sch, extension.kicad_sch]
2026-04-08 compute board 4 layer, with camera connector and small bug fixes
    [base.kicad_pcb, camera.kicad_sch, compute.kicad_pcb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]
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2026-04-16 quick backup, decided to merge compute and extension
    [base.kicad_sch, compute.kicad_pcb, compute.kicad_sch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]
2026-04-26 schema support spindle, fan , 24V, compliant with VEVOR
    [camera.kicad_sch, compute.kicad_sch, esp32.kicad_sch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]
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2026-05-05 improved powernet, fixed bugs, tuned tracks for camera
    [camera.kicad_sch, compute.kicad_pcb, compute.kicad_sch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]
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2026-05-26 fixed: uartx res to 5.1K, switch connection cross, camera connextor top side
    [camera.kicad_sch, compute.kicad_pcb, esp32.kicad_sch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]
2026-07-07 added comment chip, changed i2c resistor to 1.5K
    [compute.kicad_sch, esp32.kicad_sch, laserhead.kicad_sch]
2026-09-28 improved ability for optical inpspection usb connector and motors
    [compute.kicad_pcb]
2026-09-29 Outside of the format migration, there are only minor component/footprint updates:
    base.kicad_sch
    J2: Marked as Do Not Populate ((dnp yes)).
    J2 footprint: Switched from custom library to standard KiCad library: sockets_scanhead:motor_13pin → Connector_PinSocket_2.00mm:PinSocket_1x13_P2.00mm_Vertical
    plate.kicad_sch
    Connector footprint: Switched to standard library: mirrormotor:PinHeader_1x05_P2.00mm_Vertical → Connector_PinHeader_2.00mm:PinHeader_1x05_P2.00mm_Vertical
    Part order numbers added: Added #manf: M22-2510505, #mouser: 855-M22-2510505, and #farnell: 3226026.
    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
    [base.kicad_pcb, base.kicad_sch, mirrormotor.kicad_sch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]
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2026-10-03 added previews, fixed git ltfs
    [frontplate.kicad_pcb]
2026-10-05 fixed photodiode rendering, removed felix mount, copper fill for cylinder mount and maxwell dock
    [clbase1.kicad_pcb, clbase1.kicad_sch, felixmount.kicad_pcb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]
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2026-10-13 small fix compute pcb
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
